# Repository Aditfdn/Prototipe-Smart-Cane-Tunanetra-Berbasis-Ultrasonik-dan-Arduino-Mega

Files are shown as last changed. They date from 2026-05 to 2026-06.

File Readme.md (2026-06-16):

<h1 align="center">Rancang Bangun Tongkat Pintar guna Membantu Mobilitas dan Keselamatan Penyandang Tuna Netra Berbasis ATmega2560 melalui Sistem Deteksi Halangan dan Peringatan Getar dalam Mendukung SDG No. 10 dan 11 (Reduced Inequalities & Sustainable Cities)</h1>

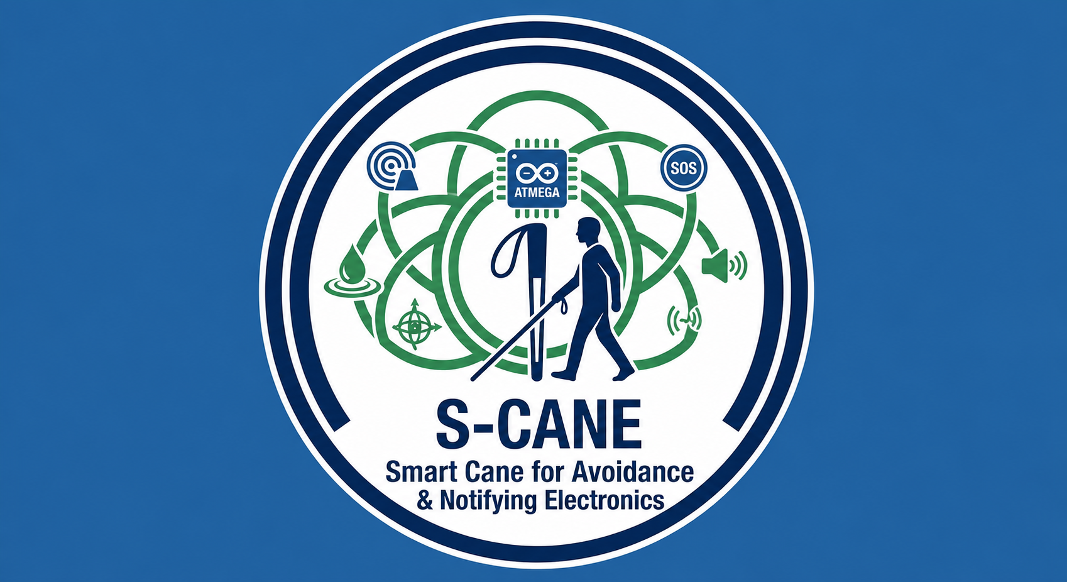
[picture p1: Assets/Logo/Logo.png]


## Deskripsi Proyek
Proyek ini mengembangkan **Tongkat Pintar (Smart White Cane)** berbasis **ATmega2560** yang dirancang untuk membantu mobilitas, keselamatan, dan kemandirian penyandang tuna netra dalam beraktivitas sehari-hari. Sistem mengintegrasikan teknologi deteksi lingkungan, peringatan taktil, serta komunikasi darurat secara real-time guna mendukung implementasi **SDG No. 10 (Reduced Inequalities)** dan **SDG No. 11 (Sustainable Cities and Communities)**.

Tongkat pintar ini memanfaatkan **sensor ultrasonik HC-SR04** untuk mendeteksi keberadaan halangan atau rintangan di depan pengguna. Selain itu, **Rain Sensor** digunakan untuk mendeteksi genangan air atau permukaan jalan yang basah sehingga pengguna dapat menghindari area yang berpotensi membahayakan. Informasi dari kedua sensor tersebut diproses oleh **mikrokontroler ATmega2560** dan diterjemahkan menjadi peringatan berupa getaran melalui **Motor Vibrator** serta bunyi melalui **Buzzer**, sehingga dapat dipahami dengan mudah oleh pengguna tuna netra.

Untuk meningkatkan aspek keselamatan, sistem dilengkapi **Panic Button** yang dapat ditekan pengguna ketika berada dalam kondisi darurat. Saat tombol ditekan, mikrokontroler akan mengaktifkan **modul SIM800L** untuk mengirimkan pesan notifikasi darurat ke akun **Telegram** yang telah terhubung sebelumnya. Fitur ini memungkinkan keluarga, pendamping, atau pihak terkait menerima informasi keadaan darurat secara cepat sehingga bantuan dapat segera diberikan.

Dengan menggabungkan sistem deteksi hambatan, deteksi genangan air, peringatan multimodal, dan komunikasi darurat berbasis Telegram, tongkat pintar ini diharapkan mampu meningkatkan aksesibilitas, keamanan, dan kualitas hidup penyandang tuna netra dalam beraktivitas di lingkungan perkotaan yang inklusif dan berkelanjutan.

## Tujuan Proyek

1. Merancang alat bantu jalan adaptif guna meningkatkan mobilitas mandiri dan keamanan penyandang tuna netra di lingkungan luar ruangan (outdoor).
2. Mengintegrasikan sensor ultrasonik (HC-SR04) dan rain sensor untuk mendeteksi rintangan fisik serta genangan air di jalan secara real-time.
3. Menerapkan sistem umpan balik ganda berupa peringatan getar (motor vibrator) dan suara (buzzer) yang intuitif bagi indra peraba dan pendengaran pengguna.
4. Menyediakan fitur keselamatan darurat berbasis GSM (SIM800L) untuk mengirimkan SMS peringatan otomatis secara real-time saat pengguna menekan tombol panik atau terdeteksi jatuh oleh sensor MPU-6050.
5. Mendukung pencapaian target SDGs global, khususnya SDG 9 (Industry, Innovation, and Infrastructure), SDG 10 (Reduced Inequalities), dan SDG 11 (Sustainable Cities and Communities).

## Support By :
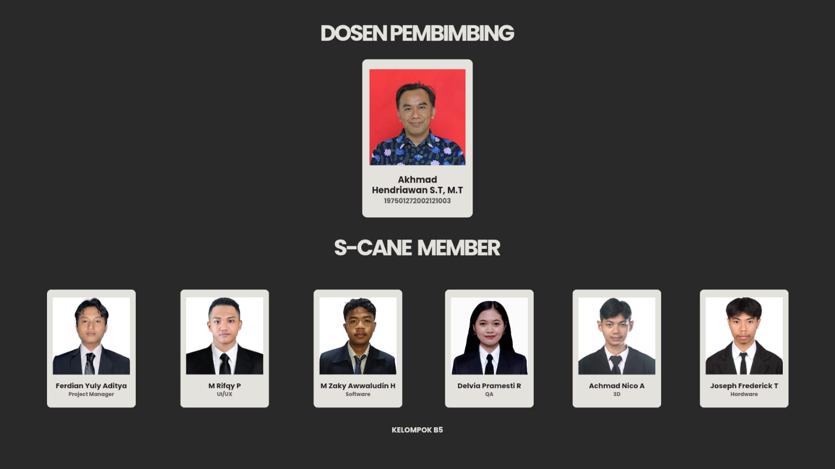
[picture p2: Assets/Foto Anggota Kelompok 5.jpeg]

> * Dosen Pengampu: Akhmad Hendriawan ST., MT. (NIP. 197501272002121003)
> * Mata Kuliah: Mikrokontroler
> * Program Studi: D4 Teknik Elektronika
> * Politeknik Elektronika Negeri Surabaya

## Anggota Tim

| Foto | NRP | Nama | Jobdesk | Akun |
| :---: | :---: | :---: | :---: | :---: |
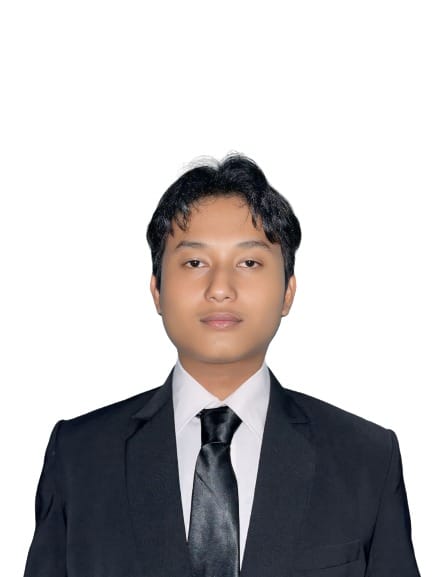
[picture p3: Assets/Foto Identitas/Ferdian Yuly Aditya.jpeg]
|  | 2124600054 | Ferdian Yuly Aditya | Project Manager | [Aditfdn](https://github.com/Aditfdn) |
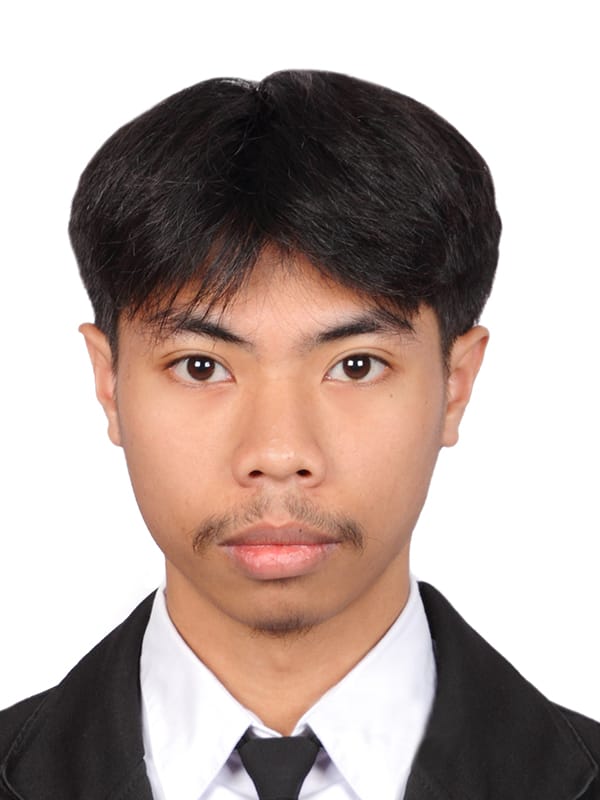
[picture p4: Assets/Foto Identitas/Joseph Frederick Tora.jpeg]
|  | 2124600039 | Joseph Frederick Tora  | Hardware Specialist | [josephtora](https://github.com/josephtora) |
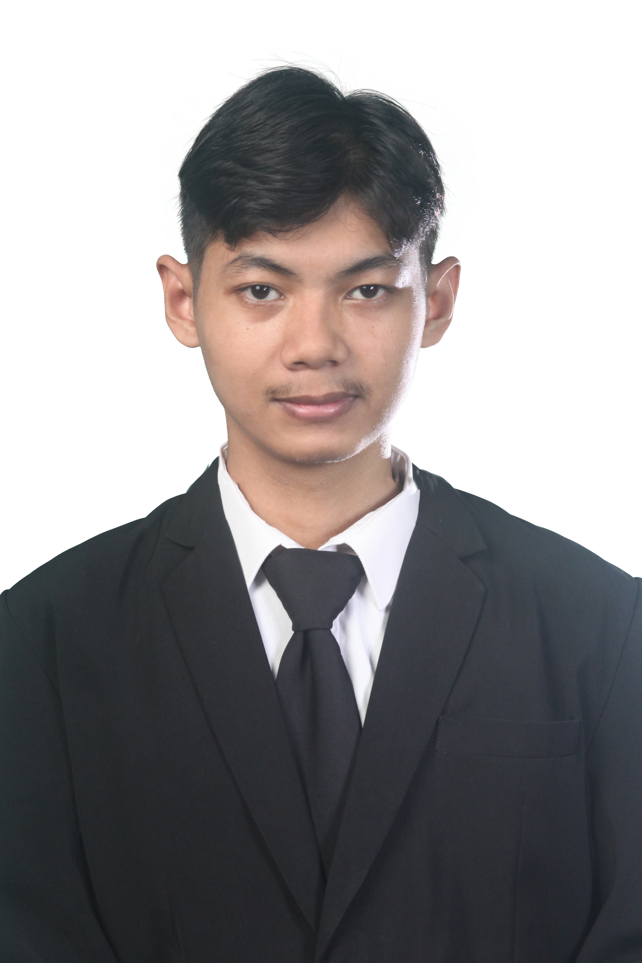
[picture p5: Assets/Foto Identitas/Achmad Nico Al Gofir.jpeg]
|  | 2124600052 | Achmad Nico Al Gofir | 3D Designer | [Oc1nn](https://github.com/Oc1nn) |
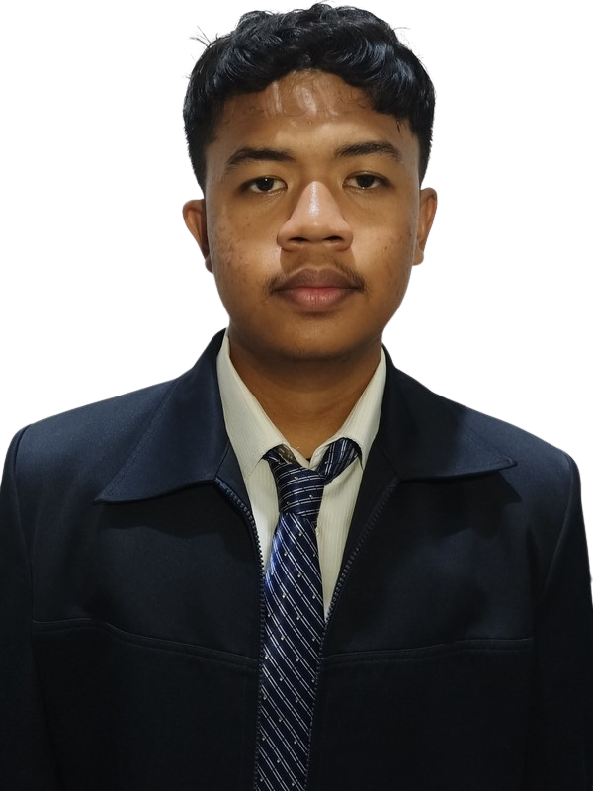
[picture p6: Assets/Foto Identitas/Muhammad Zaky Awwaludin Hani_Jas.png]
|  | 2124600055 | Muhammad Zaky Awwaludin Hani | Progammer | [Cheesejek](https://github.com/CheeseJek) |
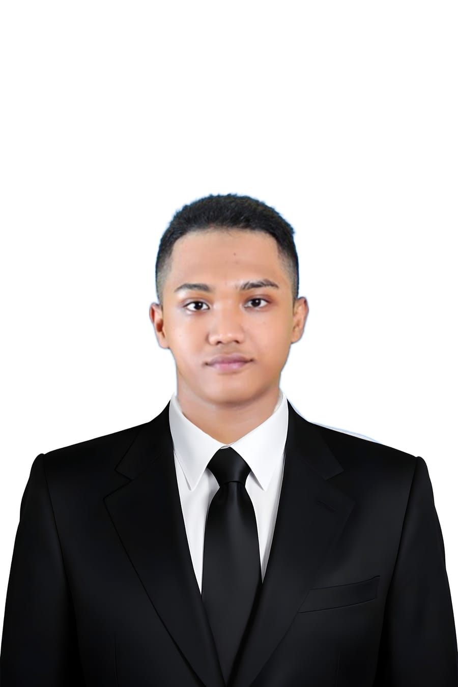
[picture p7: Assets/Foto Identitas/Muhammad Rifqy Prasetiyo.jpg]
|  | 2124600050 | Muhammad Rifqy Prasetiyo| UI/UX Designer | [Rifqypaypal](https://github.com/Rifqypaypal) |
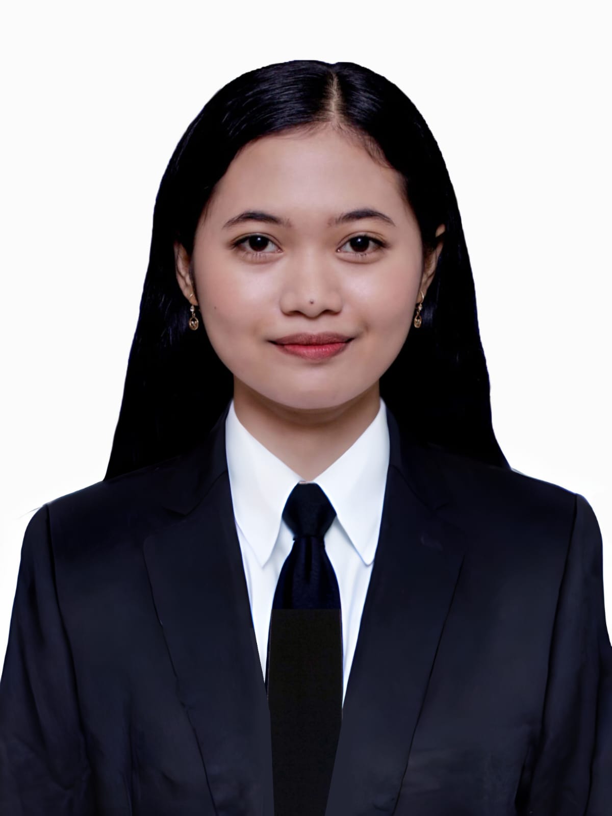
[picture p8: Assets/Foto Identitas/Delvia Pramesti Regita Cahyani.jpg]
|  | 2124600060 | Delvia Pramesti Regita Cahyani | QA | [delviap](https://github.com/delviap) |

### 🎬 Video Iklan & Promosi Produk

Simak video promosi sinematik S-CANE di bawah ini untuk melihat bagaimana teknologi inklusif berbasis ATmega2560 ini bekerja dalam membantu mobilitas mandiri penyandang tunanetra secara nyata:

https://github.com/user-attachments/assets/74869555-962a-41be-98e7-b088846499c1

> 💡 **Informasi Video:** Video promosi ini mencakup latar belakang permasalahan mobilitas disabilitas, visualisasi desain fisik casing 3D, serta demonstrasi langsung penanganan kondisi darurat (SOS) yang terintegrasi dengan Telegram pendamping.

## Komponen
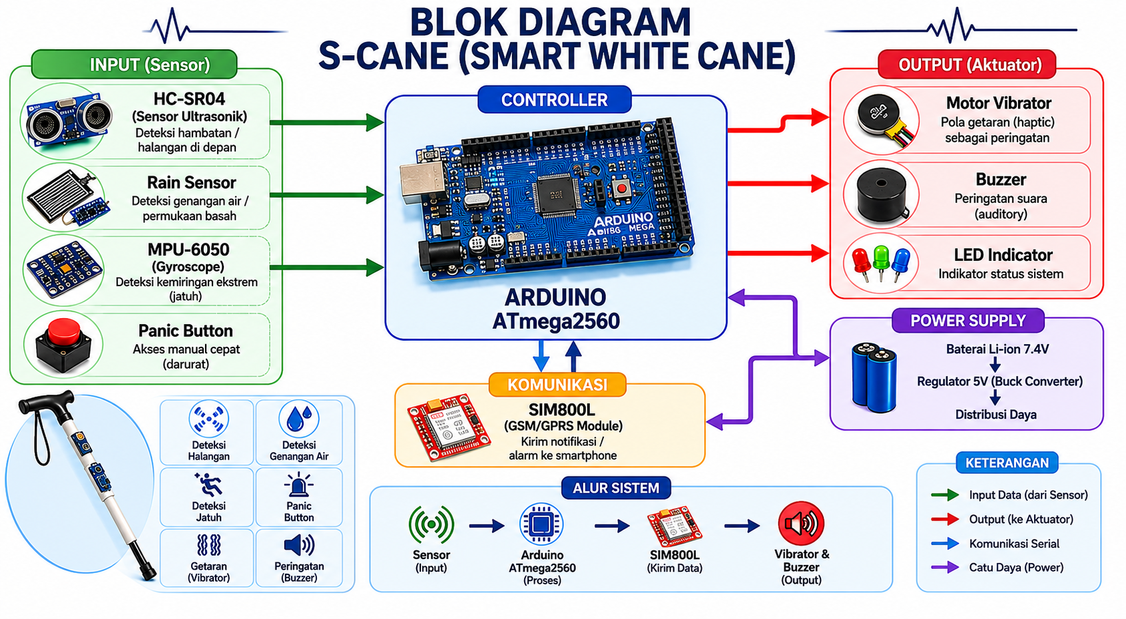
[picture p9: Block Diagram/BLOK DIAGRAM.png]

> * Rain Sensor
> * Motor Vibrator
> * Arduino ATmega 2560
> * HC-SR04 / Sensor Ultrasonik
> * MPU-6050 / Sensor Gyroscope
> * Buzzer
> * Button / Panic Button
> * SIM800L

## 🎨 3D Design & Prototyping
Berikut adalah hasil rancangan 3D dari S-CANE yang dikembangkan menggunakan software [Sebutkan Software, misal: Autodesk Inventor]:

| Tampilan Depan | Tampilan Samping |
| :---: | :---: |
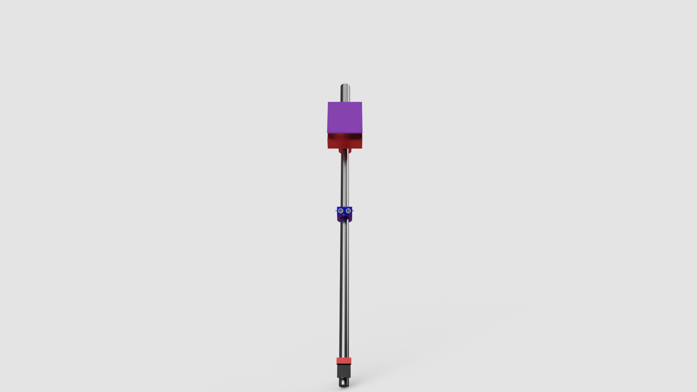
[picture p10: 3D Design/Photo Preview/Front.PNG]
Desain 1
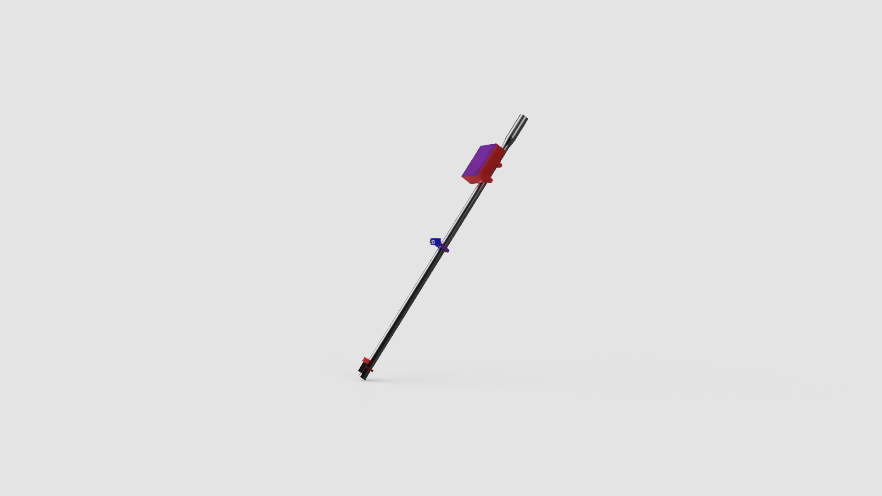
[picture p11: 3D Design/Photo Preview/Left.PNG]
Desain 2
|  |  |

> *Catatan: Desain ini dibuat untuk memastikan ergonomi dan penempatan sensor yang optimal pada tongkat.*

## 📱 UI/UX Design & Simulasi Sistem

Untuk mendukung fungsionalitas S-CANE, dikembangkan juga sebuah konsep antarmuka (UI/UX) aplikasi mobile yang berfungsi sebagai pusat kendali, monitoring status baterai, serta pelacakan lokasi pengguna tongkat secara real-time.

### 🎨 Alur Kerja Antarmuka (User Flow)
Sistem antarmuka dirancang dengan mengutamakan aksesibilitas tinggi dan kemudahan navigasi bagi keluarga atau pendamping tunanetra:

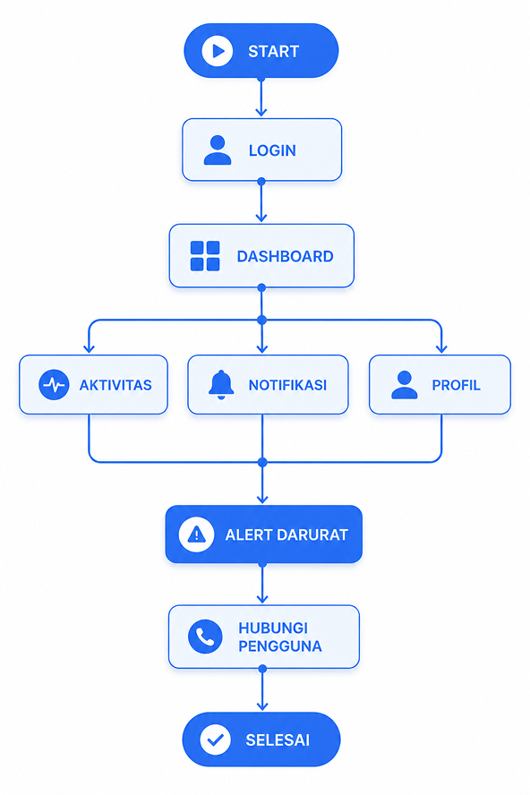
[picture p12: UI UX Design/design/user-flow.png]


1. **Dashboard Utama:** Menampilkan status konektivitas tongkat, indikator baterai ATmega2560, dan kondisi cuaca di sekitar pengguna (terintegrasi dengan *Rain Sensor*).
2. **Sistem Notifikasi Darurat:** Antarmuka khusus yang akan memicu alarm di sisi pendamping secara otomatis ketika *Panic Button* pada tongkat ditekan atau saat sensor MPU-6050 mendeteksi pengguna terjatuh.
3. **Integrasi Telegram Bot:** Simulasi pengiriman data koordinat dan pesan teks otomatis dari modul SIM800L ke aplikasi Telegram.

### 📐 Galeri Antarmuka
| Splash Screen & Login | Dashboard Monitoring | Notifikasi Darurat |
| :---: | :---: | :---: |
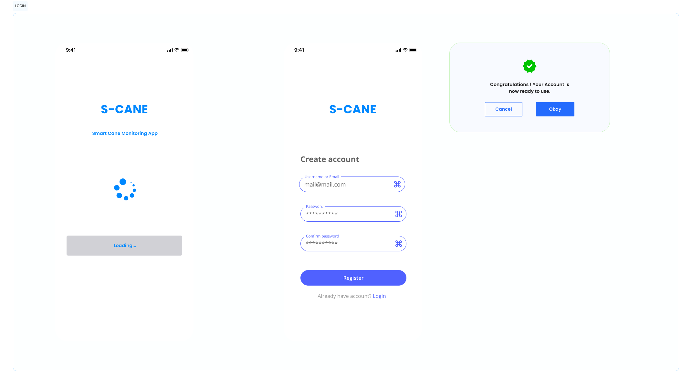
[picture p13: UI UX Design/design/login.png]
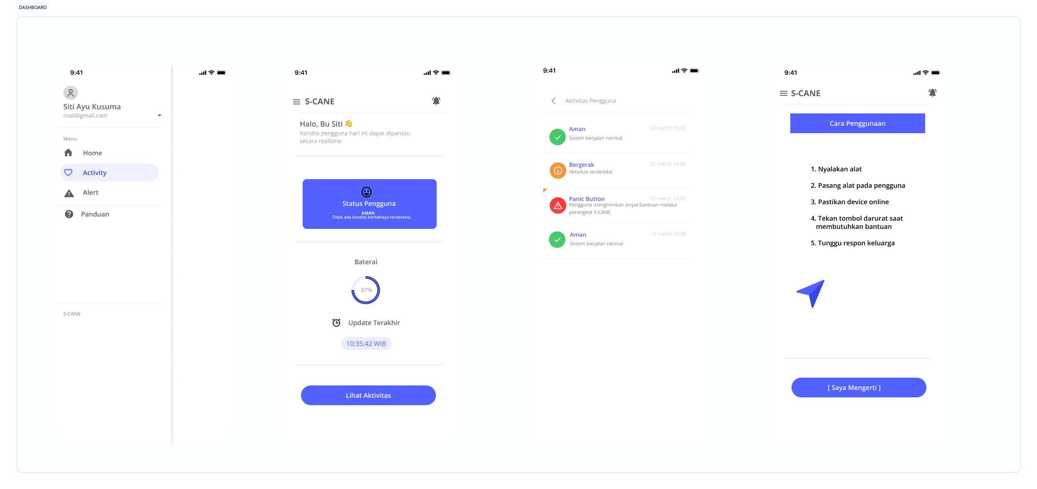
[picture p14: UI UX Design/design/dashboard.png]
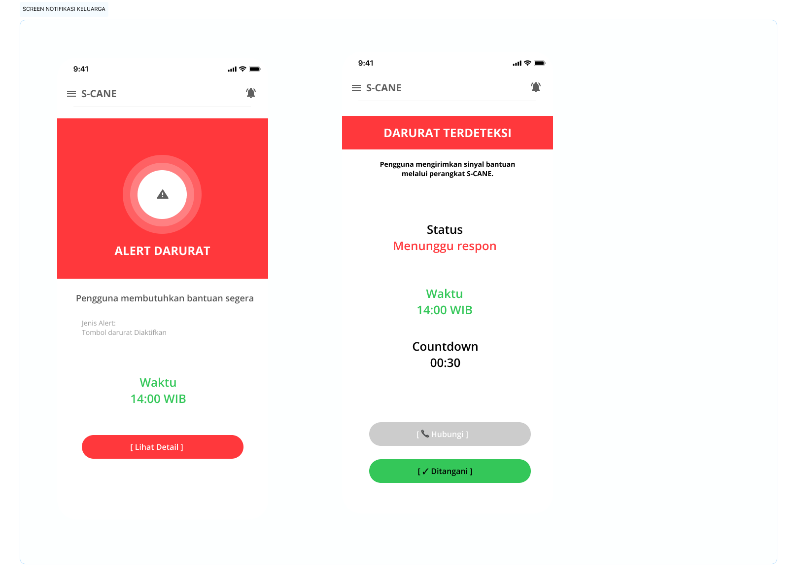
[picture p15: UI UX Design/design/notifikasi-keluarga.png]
|  |  |  |

### 📱 Panduan Penggunaan Aplikasi Mobile (UI/UX)

Desain antarmuka aplikasi mobile S-CANE tersedia secara lengkap dan interaktif di Figma. Aplikasi ini berfungsi sebagai pusat kendali bagi keluarga atau pendamping tunanetra untuk memantau kondisi pengguna tongkat secara real-time.

🔗 **Akses Desain Figma:** [S-CANE Design Mobile – Figma](https://www.figma.com/design/aeiLbA82CAR6ZKnhpcHcCP/S-CANE-Design-Mobile?node-id=0-1&t=lzUT9AXG1RDVlpGS-0)

### 🗺️ Alur Penggunaan Aplikasi

#### 1. 🚀 Splash Screen & Login
- Buka aplikasi, tampilan *splash screen* S-CANE akan muncul secara otomatis.
- Masukkan acc dan password kalian serta masukkan identitas kalian yang berisikan nama dan nomor (terdaftar telegram).
- Setelah autentikasi berhasil, pengguna akan diarahkan ke halaman **Dashboard Utama**.

#### 2. 📊 Dashboard Monitoring
- Dashboard menampilkan **status koneksi** antara aplikasi dan perangkat S-CANE secara real-time.
- Tersedia indikator **level baterai** ATmega2560 agar pendamping mengetahui kapan perangkat perlu diisi ulang.
- Kondisi lingkungan sekitar pengguna (basah/kering) yang terdeteksi oleh *Rain Sensor* ditampilkan sebagai **status cuaca jalan**.
- Seluruh informasi diperbarui secara otomatis tanpa perlu me-*refresh* halaman.

#### 3. 🆘 Sistem Notifikasi Darurat
- Ketika pengguna menekan **Panic Button** pada tongkat, aplikasi akan langsung menerima notifikasi darurat yang dikirim melalui modul **SIM800L** via Telegram.
- Notifikasi yang sama juga dipicu secara otomatis apabila sensor **MPU-6050** mendeteksi kondisi pengguna terjatuh.
- Halaman notifikasi darurat menampilkan **waktu kejadian**, **status peringatan**, serta panduan tindakan yang dapat segera diambil oleh pendamping.

#### 4. 🤖 Integrasi Telegram Bot
- Semua pesan darurat dan data status dikirimkan secara otomatis ke **akun Telegram** yang telah ditautkan pada saat login.
- Pastikan koneksi internet pada perangkat SIM800L aktif agar notifikasi dapat terkirim tanpa hambatan.
- Pendamping tidak perlu membuka aplikasi secara manual — notifikasi Telegram akan muncul langsung di layar kunci perangkat pendamping.

### ⚙️ Persyaratan Penggunaan
- Akun Telegram yang aktif untuk menerima notifikasi darurat.
- Kartu SIM dengan kuota data aktif yang terpasang pada modul **SIM800L** di perangkat S-CANE.
- Pastikan perangkat S-CANE dalam kondisi menyala dan baterai terisi cukup sebelum digunakan.

> 💡 **Catatan:** Seluruh tampilan antarmuka di atas merupakan konsep desain UI/UX yang dapat diakses dan dieksplorasi secara interaktif melalui tautan Figma di atas. Implementasi aplikasi mobile secara penuh merupakan pengembangan lanjutan dari proyek ini.

### 🎥 Video Simulasi & Demo UI/UX
Berikut adalah video demonstrasi interaktif prototipe dan jalannya aplikasi pendukung S-CANE:

https://github.com/user-attachments/assets/26122700-60ff-4c79-a8bb-ca77b9de54d8

## 🎬 Video Simulasi Sistem Keseluruhan

Selain pemodelan antarmuka, pengujian fungsionalitas logika program ATmega2560 pada proyek S-CANE ini juga didokumentasikan melalui simulasi interaktif. Video ini menampilkan bagaimana seluruh sensor (HC-SR04, Rain Sensor, MPU-6050) merespons lingkungan dan mengirimkan data secara sinkron ke aktuator serta sistem peringatan.

### 🕹️ Link Simulasi Aktif (Wokwi)

Anda dapat melihat, menjalankan, dan menguji logika program ATmega2560 pada sirkuit S-CANE secara langsung melalui browser tanpa perlu perangkat keras fisik. Klik tombol di bawah ini untuk membuka simulator:



> 💡 **Cara Menguji Alat di Wokwi:**
> 1. Klik tombol **Launch Wokwi Simulator** di atas.
> 2. Klik tombol **Start Simulation (Ikon Play Hijau)** pada halaman Wokwi.
> 3. Klik pada komponen **HC-SR04** untuk menggeser slider jarak halangan, atau tekan **Panic Button** untuk melihat respons dari Buzzer dan Motor Vibrator, klik **MPU** untuk melihat kemiringan gyroscope, serta 2 **Potensio** yang satu sebelah kiri **Rain Sensor** dan sebelah kanan sebagai Data Dummy baterai pada **UI/UX** .

### 📺 Demo Simulasi Alat

https://github.com/user-attachments/assets/4040b269-2278-43a4-b501-594f7b9bb5d2

> 💡 **Informasi Pengujian:** > * **Simulasi Input:** Simulasi pembacaan jarak rintangan dan deteksi kondisi jalan basah/genangan air.
> * **Simulasi Output:** Respons kedipan frekuensi buzzer, kekuatan getaran motor vibrator, serta simulasi pengiriman instruksi AT Command oleh modul GSM SIM800L.

## ⚙️ Simulasi Sistem Keseluruhan

Pengujian fungsionalitas dan logika program **ATmega2560** pada proyek S-CANE didokumentasikan sepenuhnya melalui rekaman video simulasi. Video ini menampilkan bagaimana seluruh sistem dari 3D, Ui Ux hingga sensor (HC-SR04, Rain Sensor, MPU-6050) merespons lingkungan dan berinteraksi secara sinkron dengan komponen output.

### 🎥 Video Demonstrasi Simulasi Alat
Berikut adalah rekaman jalannya pengujian simulasi sistem S-CANE dari awal hingga akhir:

https://github.com/user-attachments/assets/8619169c-2171-4413-95fd-638ff369f83f

---

### 🔍 Cakupan Pengujian dalam Video:
* **Simulasi Deteksi Rintangan:** Demonstrasi respons frekuensi suara *Buzzer* dan kekuatan *Motor Vibrator* saat sensor ultrasonik HC-SR04 mendeteksi objek dalam jarak dekat dan kritis.
* **Simulasi Deteksi Cuaca/Jalan Basah:** Respons sistem saat *Rain Sensor* mendeteksi adanya genangan air atau permukaan jalan yang basah.
* **Simulasi Kondisi Darurat (SOS):** Pengujian logika pengiriman pesan darurat otomatis ke UI/UX dan Telegram pendamping ketika *Panic Button* ditekan atau ketika sensor *MPU-6050* mendeteksi simulasi pengguna terjatuh.

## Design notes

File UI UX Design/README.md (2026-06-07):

# S-CANE UI/UX Design

## Overview

S-CANE (Smart Cane for Avoidance and Notifying Electronics) merupakan proyek pengembangan antarmuka aplikasi mobile yang digunakan untuk menampilkan informasi dari sistem Smart Cane.

Dokumentasi ini berisi desain antarmuka pengguna (UI) dan alur interaksi pengguna (UX) yang digunakan pada aplikasi S-CANE.

---

## Available Screens

### Splash Screen

Menampilkan identitas aplikasi saat pertama kali dijalankan.

### Login Screen

Digunakan untuk autentikasi pengguna sebelum masuk ke sistem.

### Dashboard

Halaman utama yang menampilkan informasi dan navigasi aplikasi.

### Profile Screen

Menampilkan informasi akun pengguna.

### Alert Screen

Menampilkan peringatan atau kondisi yang membutuhkan perhatian pengguna.

### Family Notification Screen

Menampilkan informasi notifikasi yang diterima keluarga.

---

## Project Structure

```text
UI UX Design/
│
├── design/
│   ├── login.png
│   ├── dashboard.png
│   ├── profile.png
│   ├── alert.png
│   ├── notifikasi-keluarga.png
│   └── user-flow.png
│
├── docs/
│   ├── uiux-design.md
│   ├── user-flow.md
│   ├── design-system.md
│   └── prototype-link.md
│
├── simulasi/
|
└── README.md
```

## Documentation

| File | Description |
| --- | --- |
| uiux-design.md | Dokumentasi antarmuka pengguna |
| user-flow.md | Alur interaksi pengguna |
| design-system.md  | Panduan desain dan komponen |
| prototype-link.md | Link desain Figma |

---

## Design Tool

Figma

Prototype:
https://www.figma.com/design/aeiLbA82CAR6ZKnhpcHcCP/S-CANE-Design-Mobile

---

## Purpose

Dokumentasi ini dibuat sebagai bagian dari pengembangan proyek S-CANE dan digunakan sebagai referensi dalam proses implementasi antarmuka aplikasi.

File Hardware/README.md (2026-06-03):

# Schematic

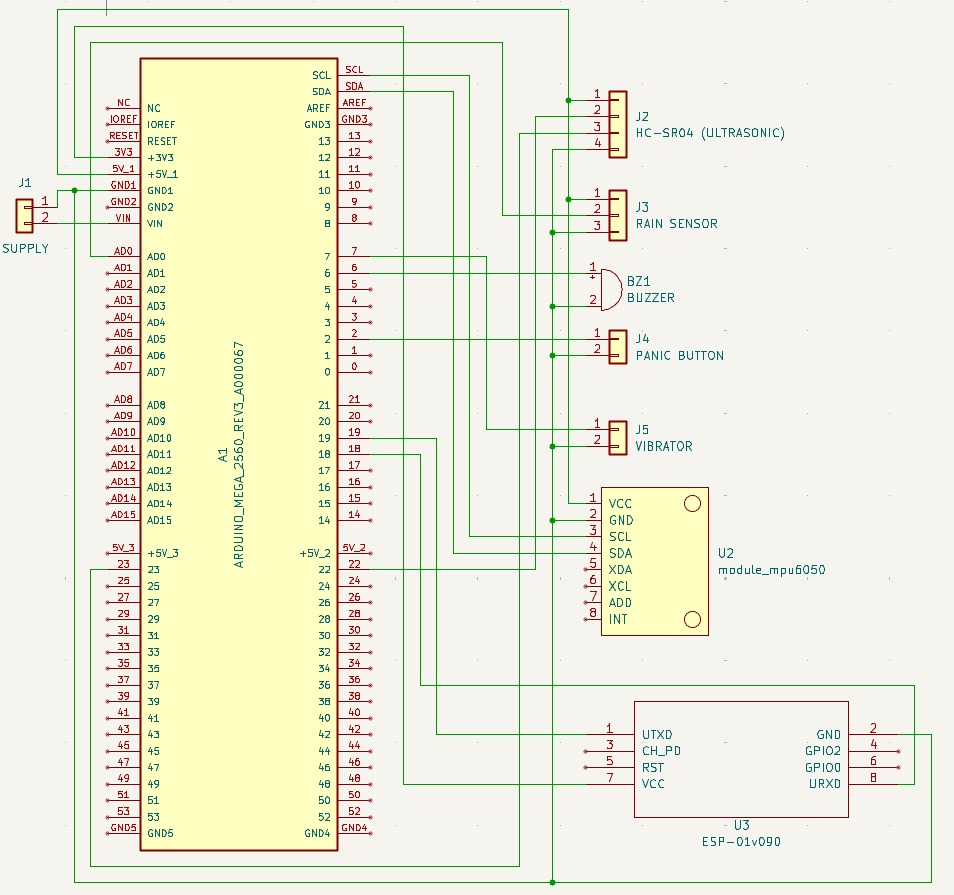
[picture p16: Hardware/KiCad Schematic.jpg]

# 3D View

## Top View
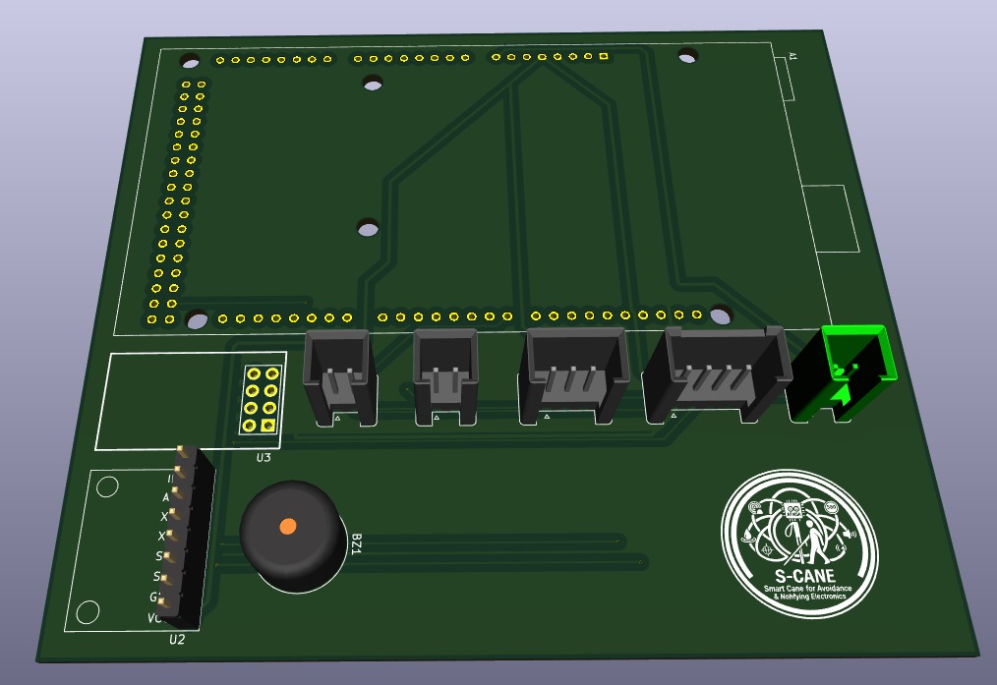
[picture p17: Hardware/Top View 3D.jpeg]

## Bottom View
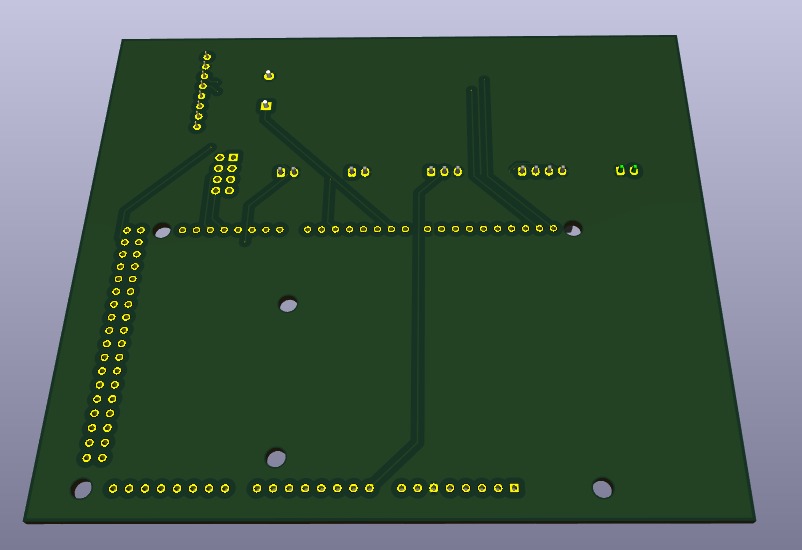
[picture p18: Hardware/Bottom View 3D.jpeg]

# PCB Layer

## Front & Back Layer
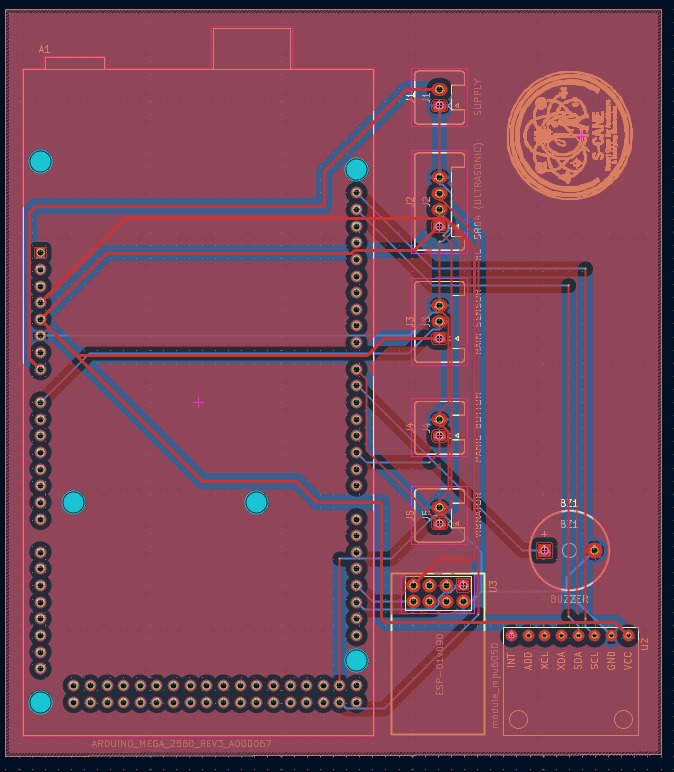
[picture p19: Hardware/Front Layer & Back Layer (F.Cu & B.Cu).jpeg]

## Front Layer
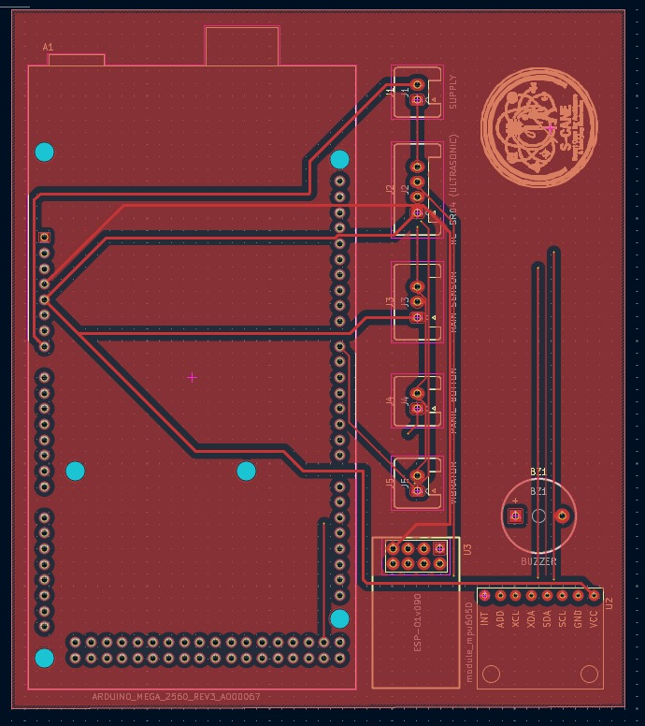
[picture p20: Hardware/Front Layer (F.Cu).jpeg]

## Back Layer
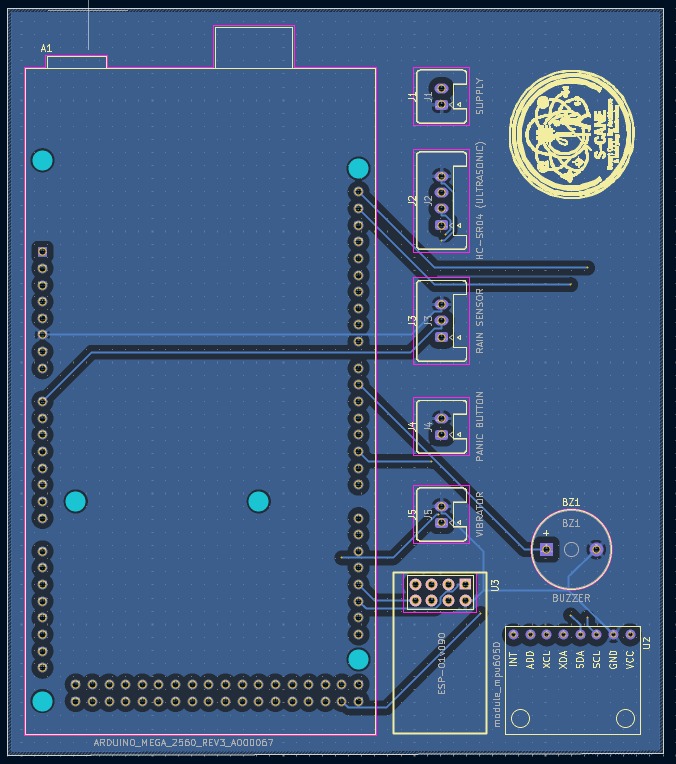
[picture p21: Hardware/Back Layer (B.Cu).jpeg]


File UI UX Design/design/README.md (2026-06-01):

# Design Assets

Folder ini berisi seluruh aset desain antarmuka aplikasi S-CANE.

## Screens

* login.png
* dashboard.png
* profile.png
* alert.png
* notifikasi-keluarga.png

## User Flow

* user-flow.png

Seluruh desain dibuat menggunakan Figma sebagai media perancangan antarmuka pengguna.

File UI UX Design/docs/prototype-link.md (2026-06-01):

# Prototype Link

## S-CANE Mobile Design Prototype

Link Figma:

https://www.figma.com/design/aeiLbA82CAR6ZKnhpcHcCP/S-CANE-Design-Mobile?node-id=0-1&t=hH0QHacxM52goHAf-1

## Deskripsi

Prototype ini berisi desain antarmuka aplikasi S-CANE yang digunakan sebagai media visualisasi sistem.

Halaman yang tersedia pada prototype:

* Splash Screen
* Login Screen
* Dashboard
* Profile Screen
* Screen Alert
* Screen Notifikasi Keluarga

## Tujuan

Prototype digunakan untuk:

1. Menampilkan rancangan antarmuka aplikasi.
2. Membantu proses evaluasi desain sebelum implementasi.
3. Menunjukkan alur interaksi pengguna pada sistem S-CANE.
4. Menjadi referensi pengembangan antarmuka aplikasi.

## Catatan

Desain pada Figma digunakan sebagai acuan utama dalam proses pengembangan tampilan aplikasi S-CANE.

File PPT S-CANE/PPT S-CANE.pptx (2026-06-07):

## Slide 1

SMART CANE

Detect, Alert, Protect.

B5

Alert,

Dosen Pengampu
Akhmad Hendriawan, ST.,MT
197501272002121003

Muhammad Rifqy Prasetiyo
2124600050
UI/UX Designer

Delvia Pramesti Regita Cahyani
2124600060
QA

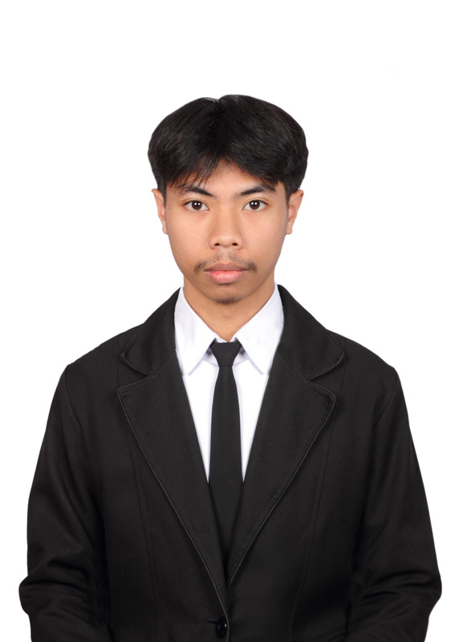
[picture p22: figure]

Joseph Fredercik Tora
2124600039
Hardware

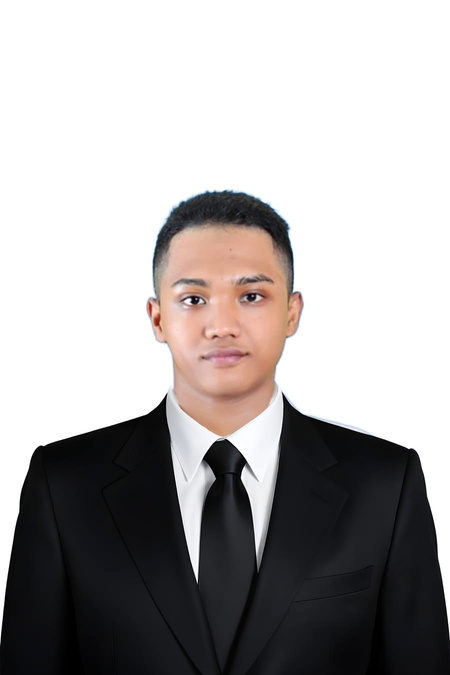
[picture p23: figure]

Achmad Nico Al Gofir
2124600052
3D Designer

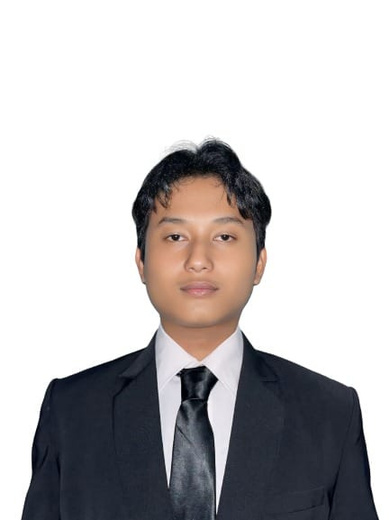
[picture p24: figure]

Ferdian Yuly Aditya
2124600054
Project Manager

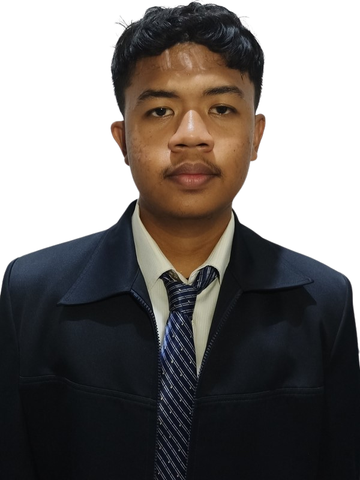
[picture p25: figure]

Muhammad Zaky Awwaludin H
2124600055
Progammer

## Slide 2

MIND-MAP

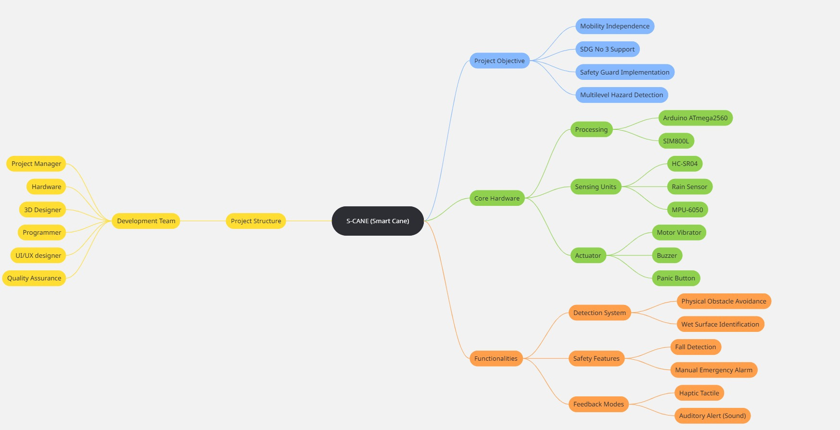
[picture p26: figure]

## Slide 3

Kesimpulan penting dari ketiga permasalahan tersebut adalah bahwa trotoar di berbagai wilayah belum memberikan ruang yang aman bagi penyandang tunanetra akibat alih fungsi lahan oleh parkir liar dan pedagang, buruknya pemeliharaan infrastruktur, serta kesalahan desain pembangunan guiding block yang justru menjebak dan membahayakan keselamatan. Hal ini menunjukkan masih lemahnya penegakan hukum dan minimnya pelibatan komunitas difabel dalam perencanaan fasilitas publik, sehingga hak aksesibilitas yang inklusif dan ramah bagi teman-teman disabilitas belum terpenuhi dengan layak.

THE PROBLEM

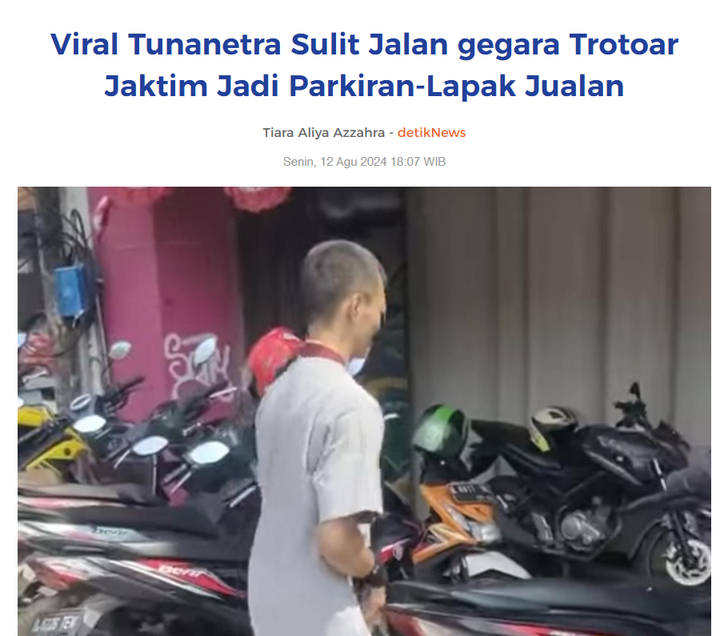
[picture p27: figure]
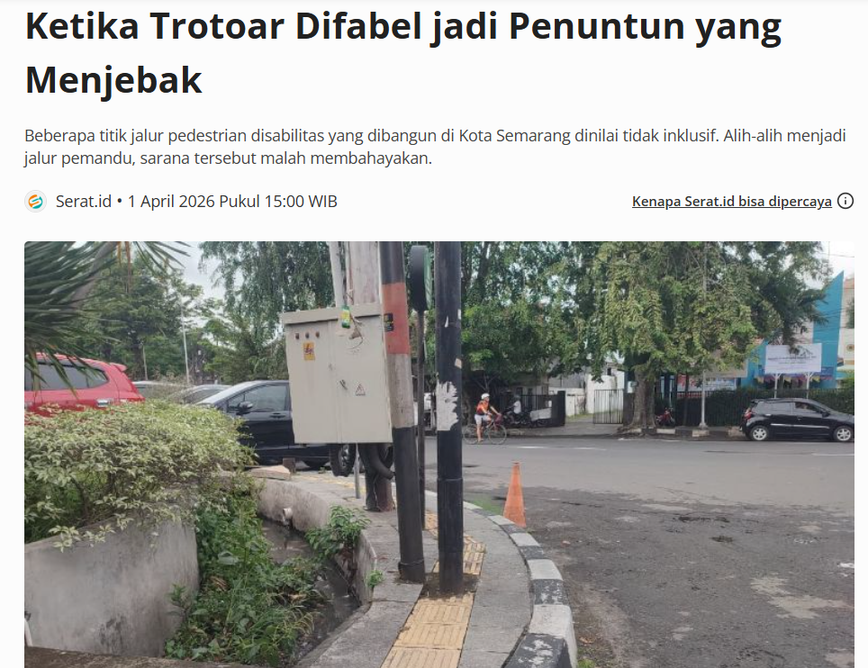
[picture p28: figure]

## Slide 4

ROOT CAUSE & MATRIK KEPUTUSAN

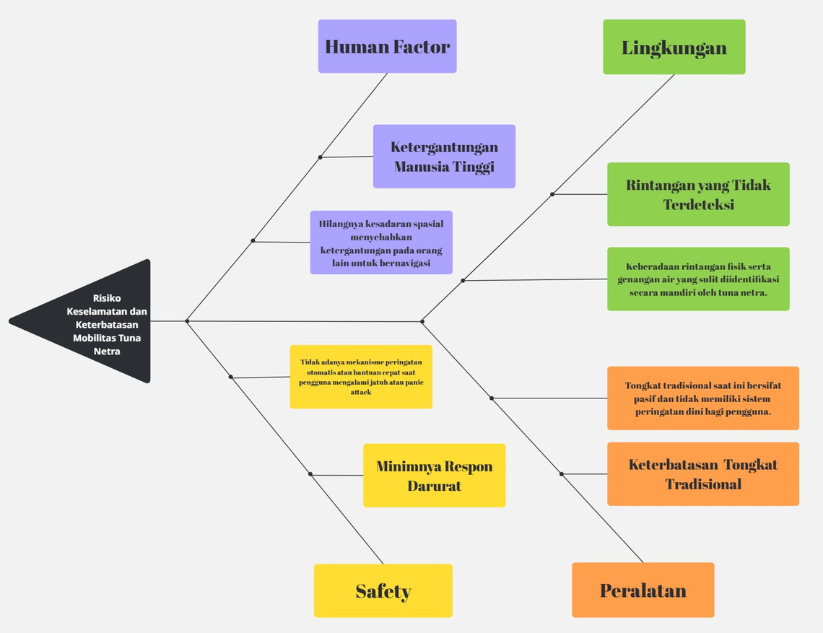
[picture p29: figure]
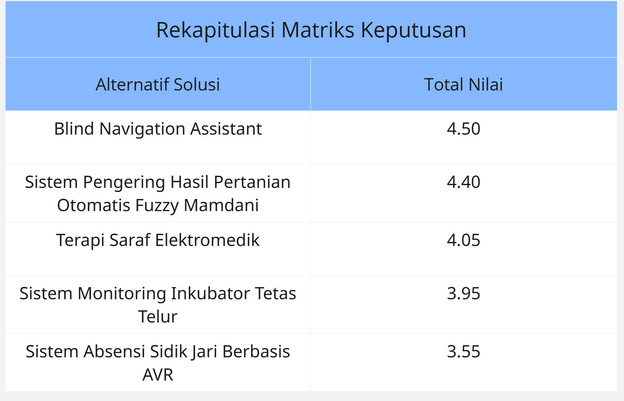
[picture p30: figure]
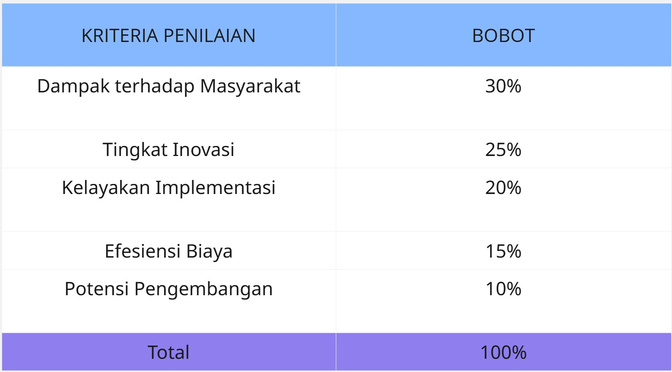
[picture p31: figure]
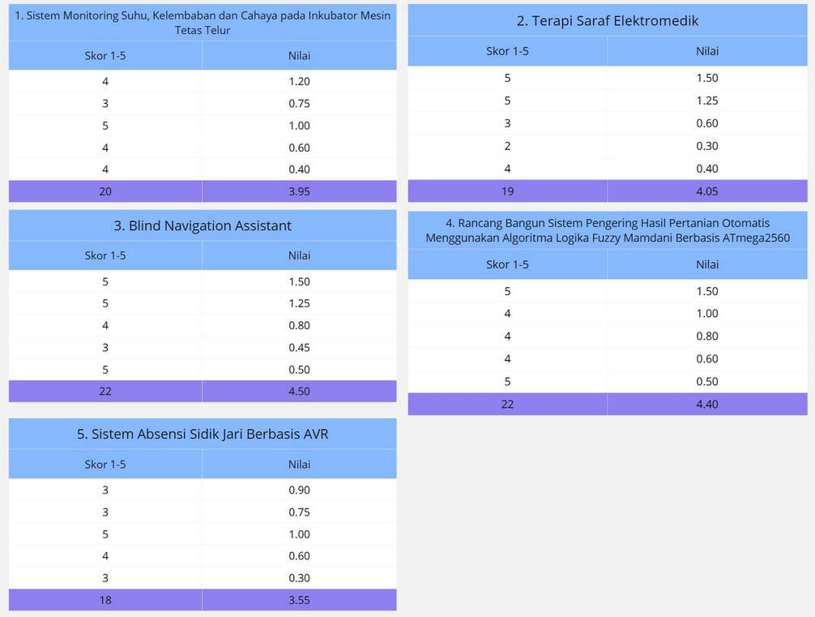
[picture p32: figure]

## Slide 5

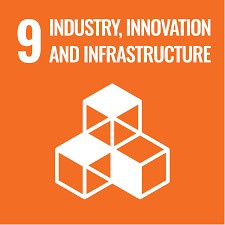
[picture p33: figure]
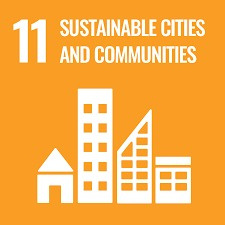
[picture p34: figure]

SDG 9 - Industry, Innovation, and Infrastructure

Target 9.5 :
  - Enhance scientific research and upgrade technological capabilities.
Justifikasi :
  - S-CANE mengintegrasikan mikrokontroler ATmega2560 dengan IoT (ESP8266) sebagai bentuk inovasi teknologi tepat guna untuk memodernisasi alat bantu konvensional.

SDG 10 - Reduced Inequalities

Target 10.2 :
  - Empower and promote the social, economic, and political inclusion of all, irrespective of disability.
Justifikasi :
  - S-CANE bertindak sebagai assistive technology yang memandirikan mobilitas tuna netra, mengurangi ketergantungan pada orang lain, dan memangkas kesenjangan sosial.

SDG 11 - Sustainable Cities and Communities

Target 11.2 :
  - Provide access to safe, affordable, accessible and sustainable transport systems for all, notably older persons and persons with disabilities.
Justifikasi :
  - Melalui deteksi halangan otomatis dan genangan air, proyek ini mendukung terciptanya infrastruktur lingkungan kota yang inklusif dan aman bagi kelompok rentan.

SDGs IMPACT

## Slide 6

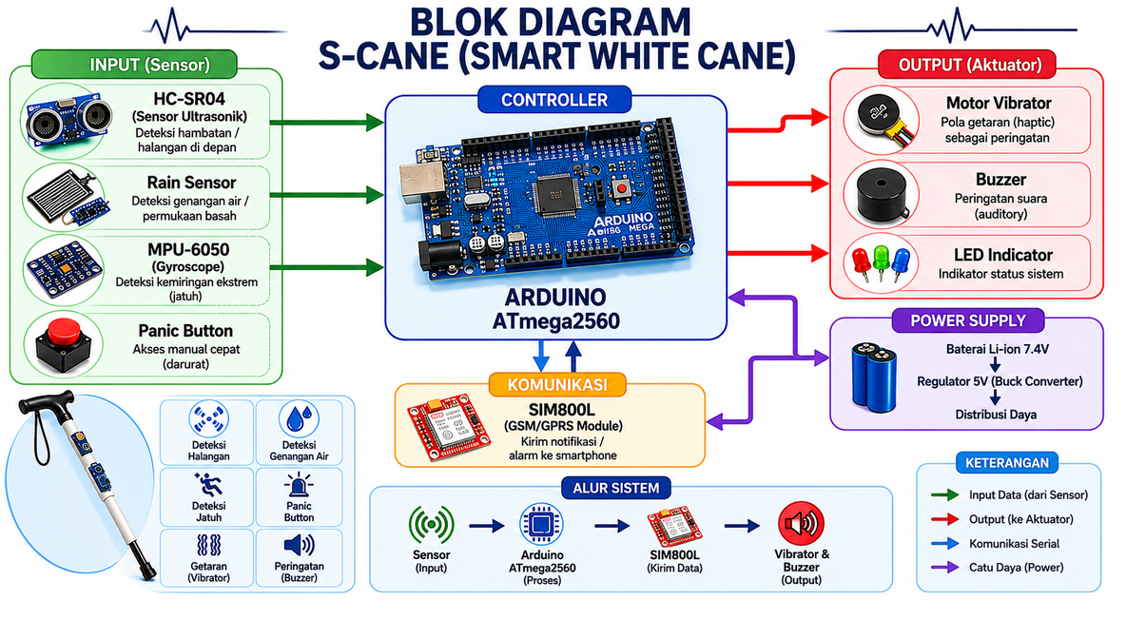
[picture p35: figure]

BLOK DIAGRAM

TABEL I/O

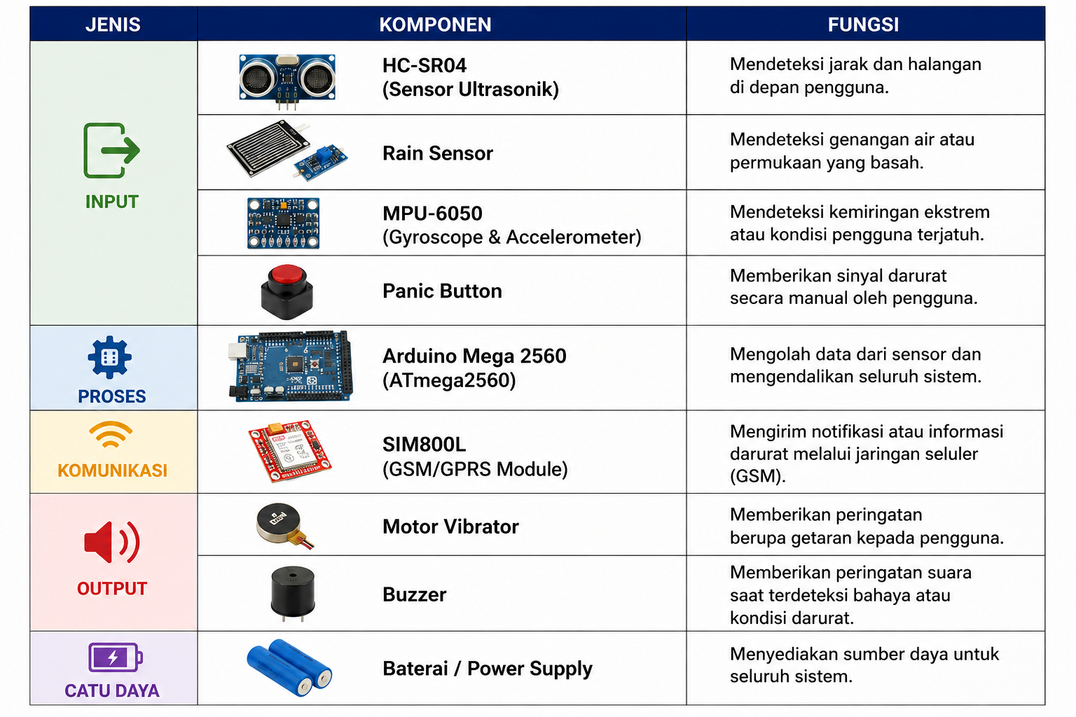
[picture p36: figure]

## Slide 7

UI UX Design

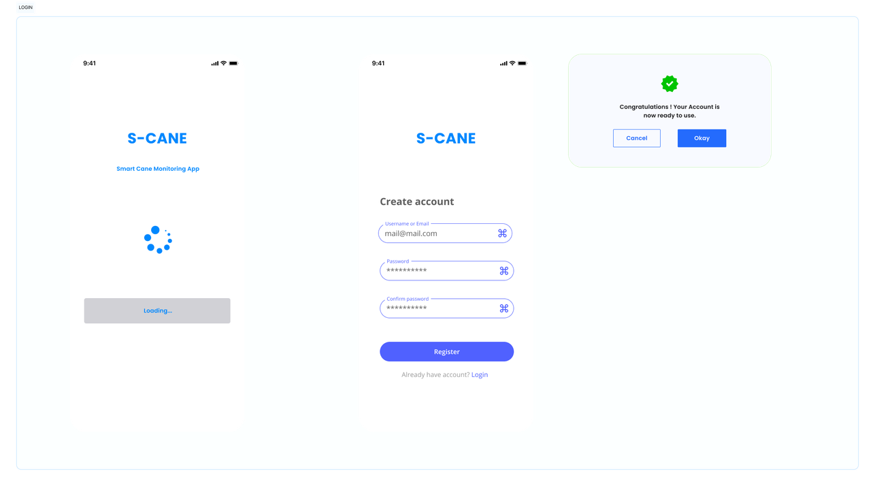
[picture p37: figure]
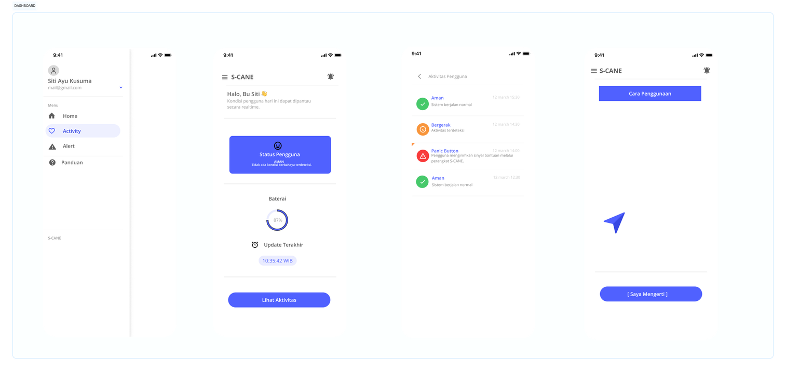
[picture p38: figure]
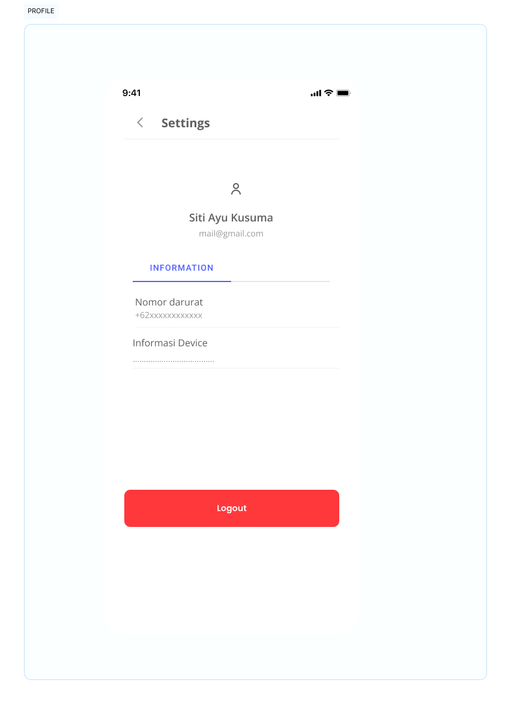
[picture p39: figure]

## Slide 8

Pin Mapping & Anggaran

KOMPONEN | JUMLAH | HARGA
Arduino Mega 2560 | 1 | Rp170.000
Sensor Ultrasonik HC-SR04 | 1 | Rp18.000
Modul Sensor Hujan (Rain Sensor) | 1 | Rp18.000
Sensor Gyroscope MPU-6050 | 1 | Rp30.000
SIM800L | 1 | Rp70.000
Mini Push Button (Panic) | 1 | Rp1.000
Active Buzzer 5V | 1 | Rp3.000
Coin Vibration Motor 5V | 1 | Rp5.000
Baterai 18650 & Holder | 1 | Rp40.000
Kabel Jumper, PCB Bolong dan lain lain | 1 | Rp25.000
Total | 10 | Rp380.000

KOMPONEN | PIN KOMPONEN | PIN ATmega2560 (Arduino Mega)
HC-SR04 | TRIG ECHO | 22 23
Rain Sensor (Simulasi: Potensio) | SIG / AO | A0
MPU-6050 (Gyroscope) | SDA SCL | 20 (SDA) 21 (SCL)
Panic Button | Out / Kaki 1 | 2 (INT0)
Motor Vibrator (Simulasi: LED) | Anoda (+) | 7 (PWM)
Buzzer | Positif (+) | 6 (PWM)
SIM800l | TX RX | 18 (TX1) 19 (RX1)

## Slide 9

ACTIVITY LOG


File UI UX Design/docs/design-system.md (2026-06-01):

# Design System Documentation

## Warna

### Biru

Digunakan pada:

* Tombol utama
* Header
* Informasi status

Tujuan:
Memberikan kesan aman dan konsisten.

### Merah

Digunakan pada:

* Alert
* Peringatan

Tujuan:
Menarik perhatian pengguna terhadap kondisi penting.

### Putih

Digunakan sebagai warna latar utama.

Tujuan:
Menjaga tampilan tetap bersih dan mudah dibaca.

---

# Typography

Jenis huruf yang digunakan mengikuti standar antarmuka mobile modern dengan tampilan sederhana dan mudah dibaca.

---

# Komponen Utama

## Button

Digunakan untuk:

* Login
* Logout
* Tindakan pada Alert

## Card

Digunakan untuk:

* Menampilkan informasi
* Menampilkan status

## Navigation

Digunakan untuk berpindah antar halaman pada aplikasi.

---

# Konsistensi Desain

Seluruh halaman menggunakan:

* Warna utama yang sama
* Bentuk tombol yang seragam
* Tata letak sederhana
* Struktur informasi yang konsisten

Hal ini bertujuan untuk meningkatkan kemudahan penggunaan aplikasi.

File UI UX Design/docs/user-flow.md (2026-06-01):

# User Flow Documentation

## Alur Penggunaan Aplikasi

Splash Screen
↓
Login
↓
Dashboard

Dari Dashboard pengguna dapat membuka:

* Profile
* Alert
* Notifikasi Keluarga

---

## Skenario Penggunaan

### Skenario 1

1. Pengguna membuka aplikasi.
2. Splash Screen ditampilkan.
3. Pengguna melakukan Login.
4. Sistem menampilkan Dashboard.

### Skenario 2

1. Pengguna berada pada Dashboard.
2. Sistem menampilkan Alert.
3. Pengguna melihat informasi kondisi yang diberikan sistem.

### Skenario 3

1. Sistem mengirimkan notifikasi.
2. Informasi ditampilkan pada Screen Notifikasi Keluarga.
3. Keluarga dapat melihat detail kondisi yang diterima.

### Skenario 4

1. Pengguna membuka halaman Profile.
2. Pengguna melihat informasi akun.
3. Pengguna dapat melakukan Logout.

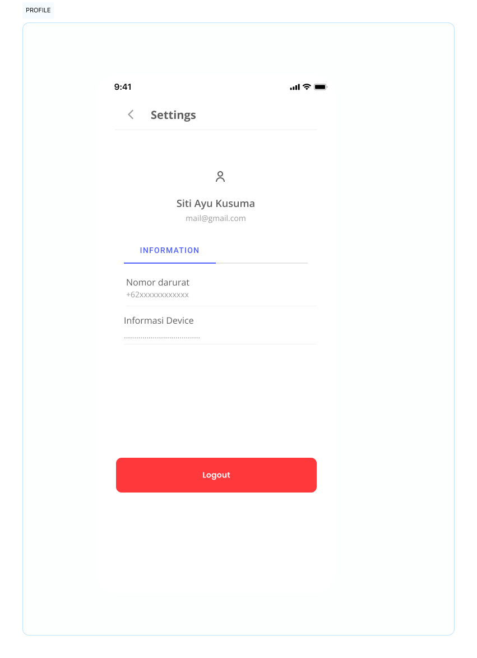
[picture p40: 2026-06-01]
UI UX Design/design/profile.png

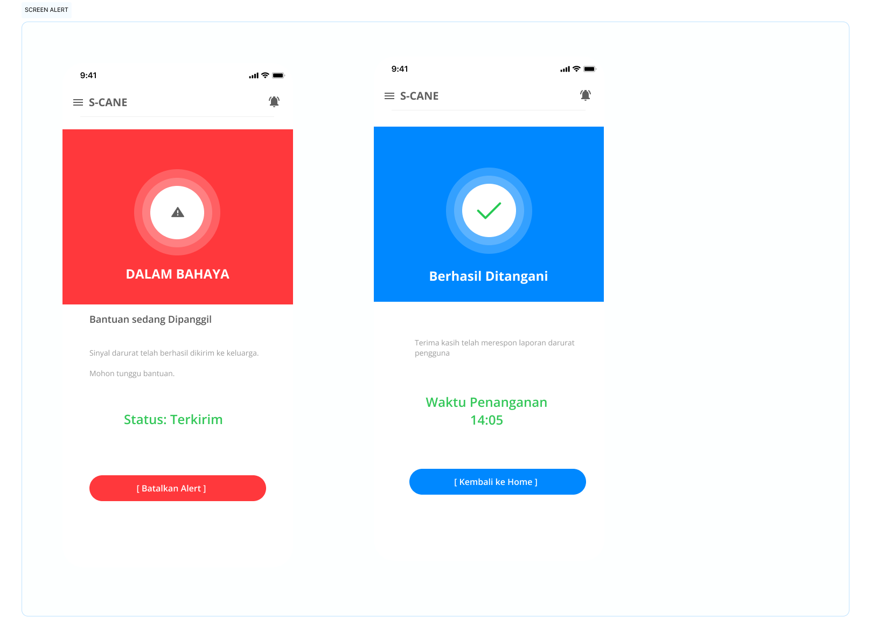
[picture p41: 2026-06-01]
UI UX Design/design/alert.png

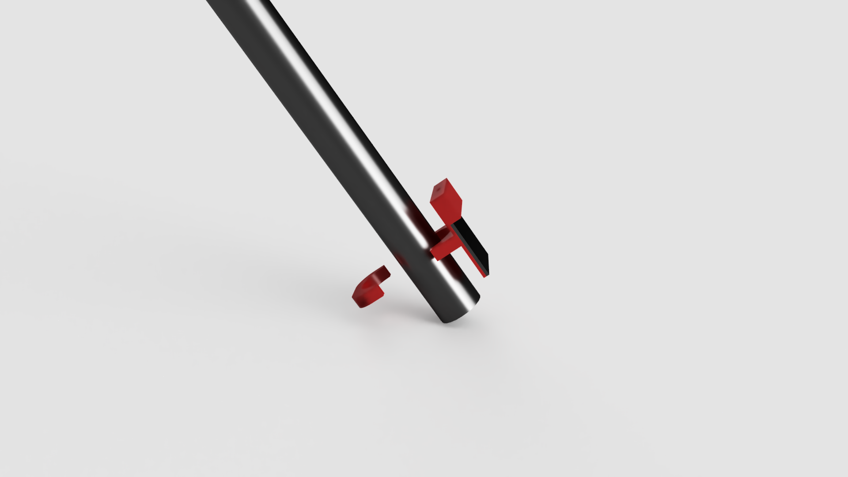
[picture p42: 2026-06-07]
3D Design/Photo Preview/Rain Sensor.PNG

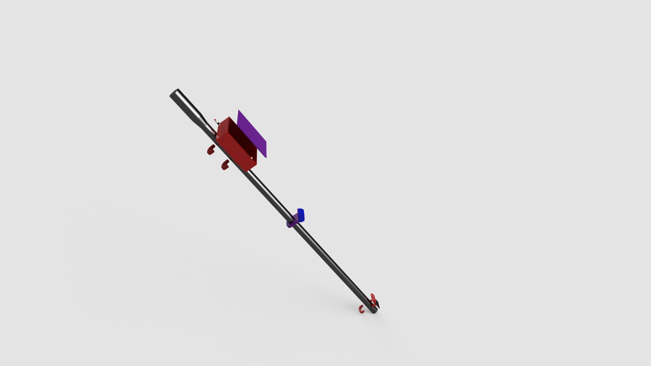
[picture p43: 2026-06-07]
3D Design/Photo Preview/Right.png

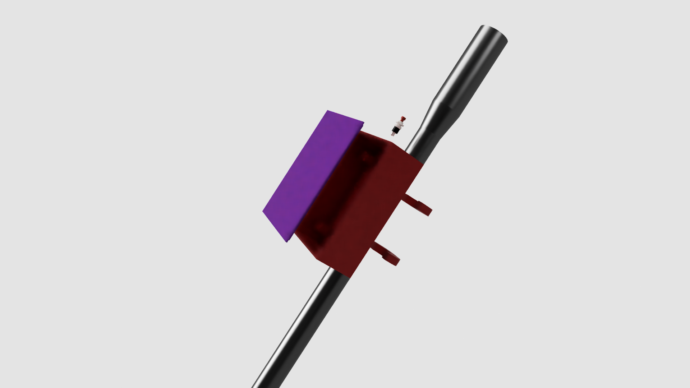
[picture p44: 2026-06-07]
3D Design/Photo Preview/Master Box.png

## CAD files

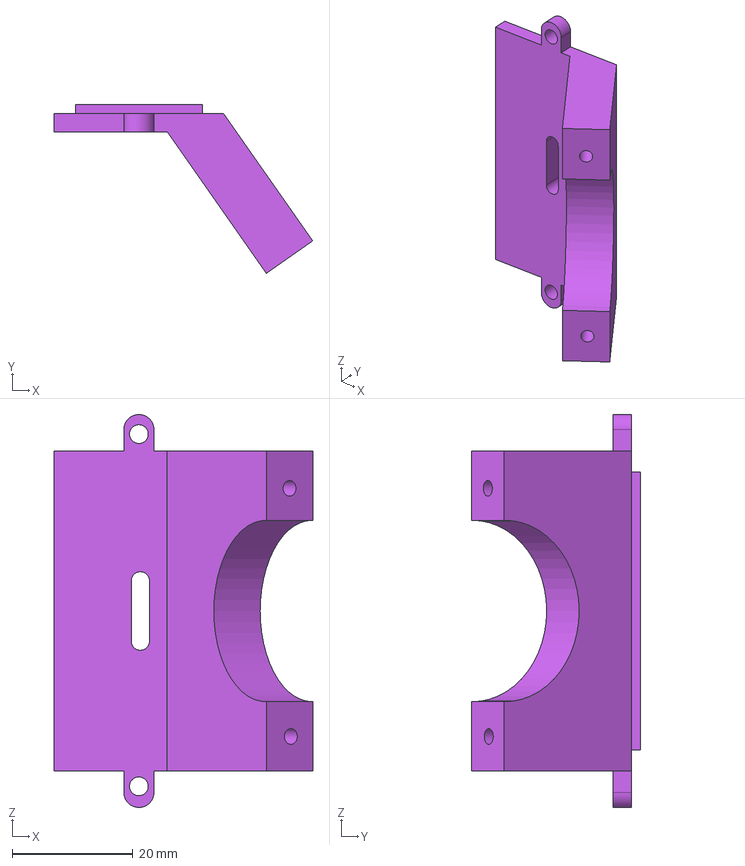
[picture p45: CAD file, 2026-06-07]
3D Design/3D File/Ultrasonic Back Cover.step
42.8 x 27.9 x 65.0 mm

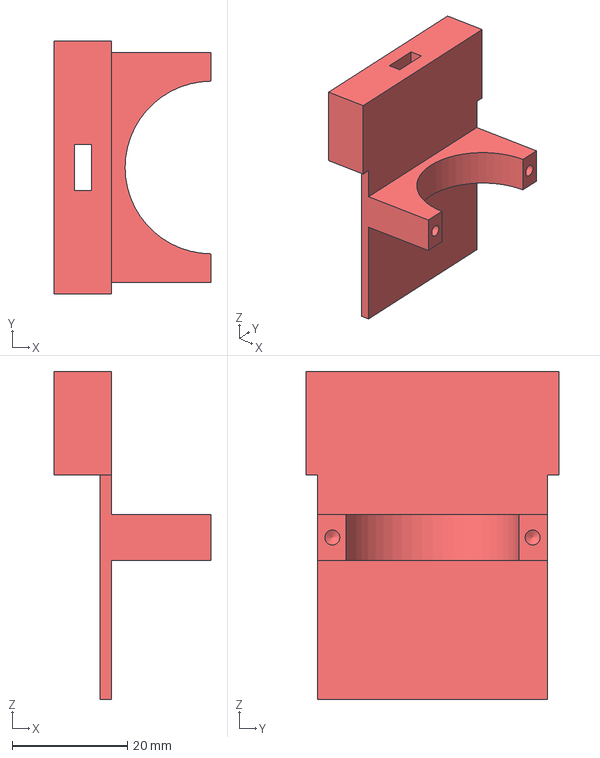
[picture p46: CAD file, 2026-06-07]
3D Design/3D File/Rain Sensor Case.step
27.2 x 44.0 x 57.0 mm

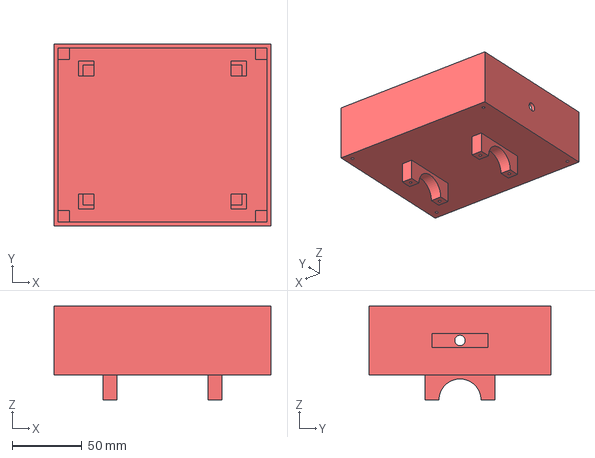
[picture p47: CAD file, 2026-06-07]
3D Design/3D File/Master Box.step
155.0 x 130.0 x 66.9 mm

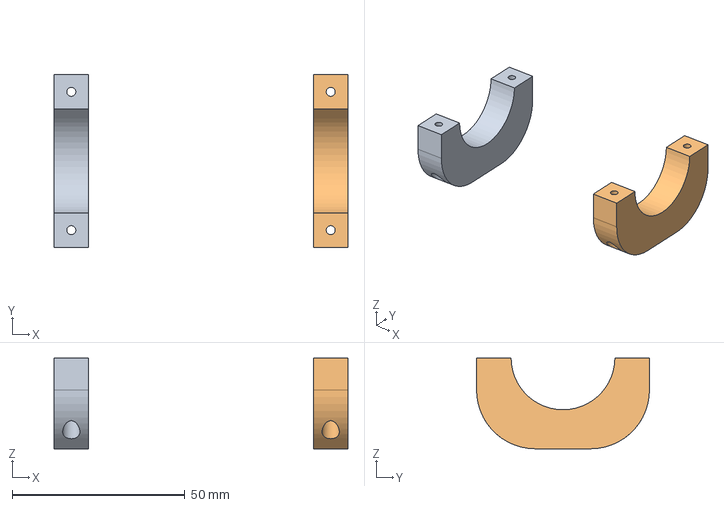
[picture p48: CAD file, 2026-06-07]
3D Design/3D File/Master Clamp.step
85.0 x 50.0 x 26.2 mm

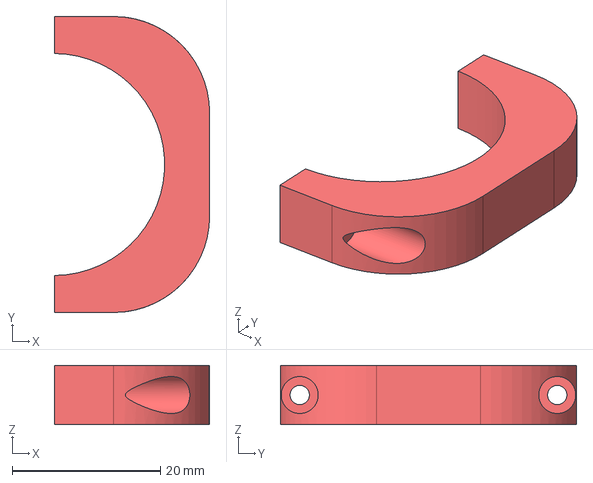
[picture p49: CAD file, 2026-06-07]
3D Design/3D File/Rain Sensor Clamp.step
21.0 x 40.0 x 8.00 mm

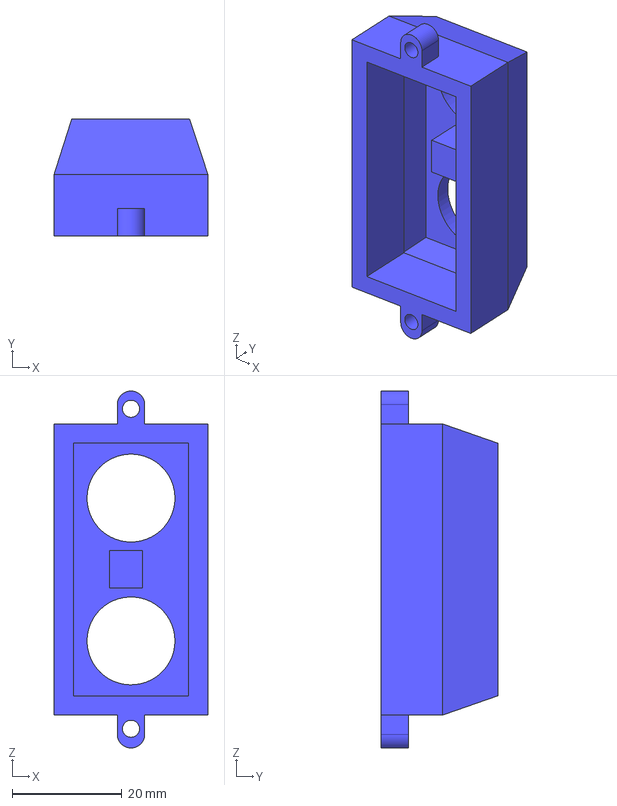
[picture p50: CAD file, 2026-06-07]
3D Design/3D File/Ultrasonic Front Cover.step
28.0 x 21.2 x 65.0 mm

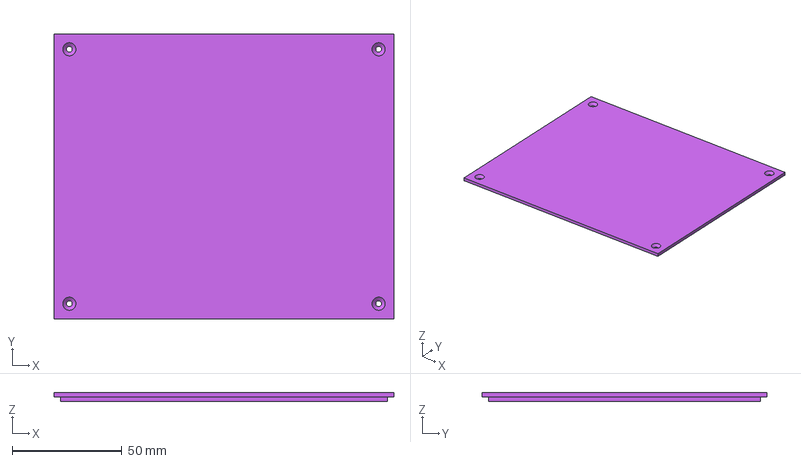
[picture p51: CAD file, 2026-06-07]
3D Design/3D File/Master Front Cover.step
155.0 x 130.0 x 4.00 mm

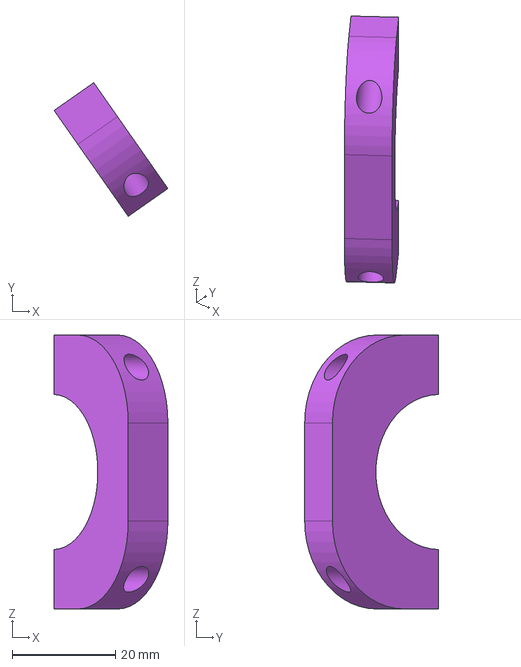
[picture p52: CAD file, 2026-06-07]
3D Design/3D File/Ultrasonic Clamp.step
22.0 x 25.9 x 53.0 mm

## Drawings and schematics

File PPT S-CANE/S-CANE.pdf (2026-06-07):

## Detect, Alert, Protect. SMART CANE

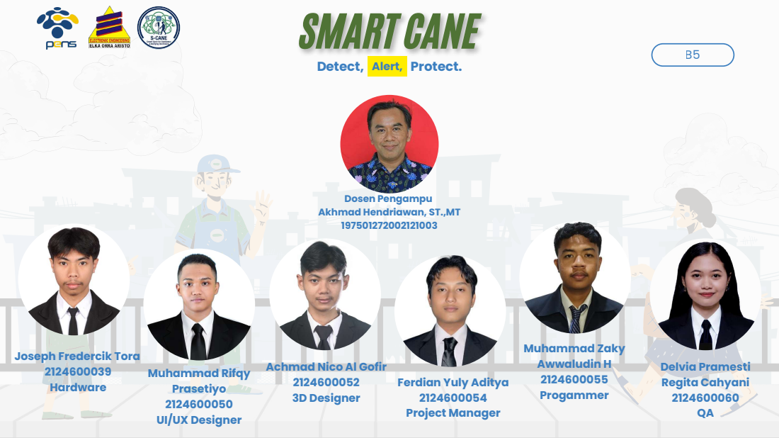
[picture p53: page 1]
Muhammad Zaky Awwaludin H 2124600055 Progammer; Delvia Pramesti Regita Cahyani 2124600060 QA; Joseph Fredercik Tora 2124600039 Hardware; Alert,

Dosen Pengampu
Akhmad Hendriawan, ST.,MT

Achmad Nico Al Gofir
3D Designer

Muhammad Rifqy
Prasetiyo
UI/UX Designer

Ferdian Yuly Aditya
Project Manager

# MIND-MAP

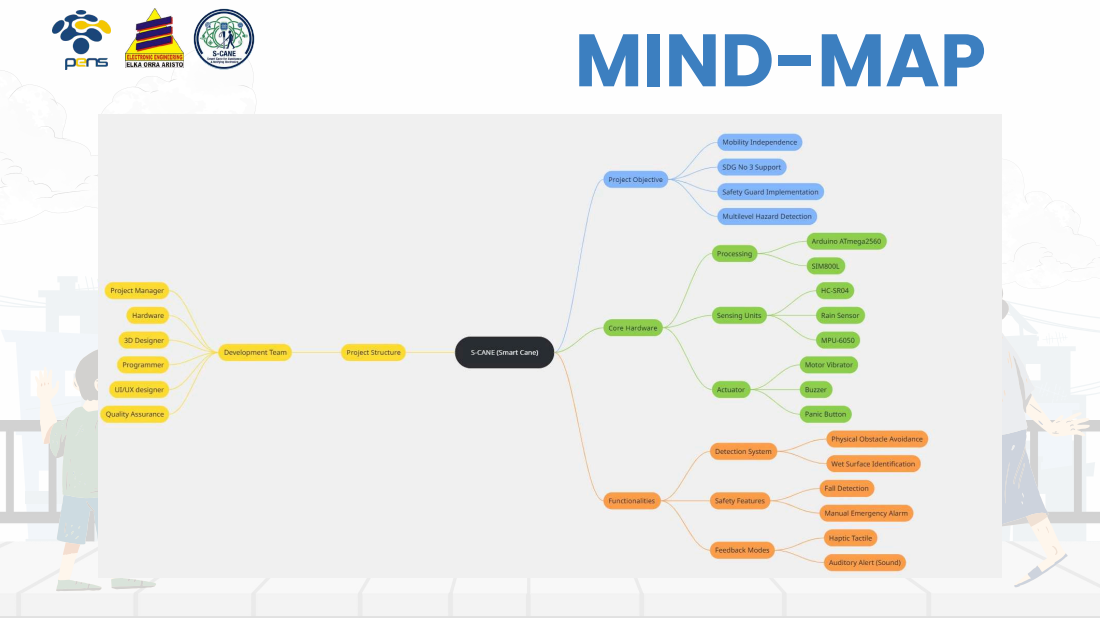
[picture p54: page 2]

# THE PROBLEM

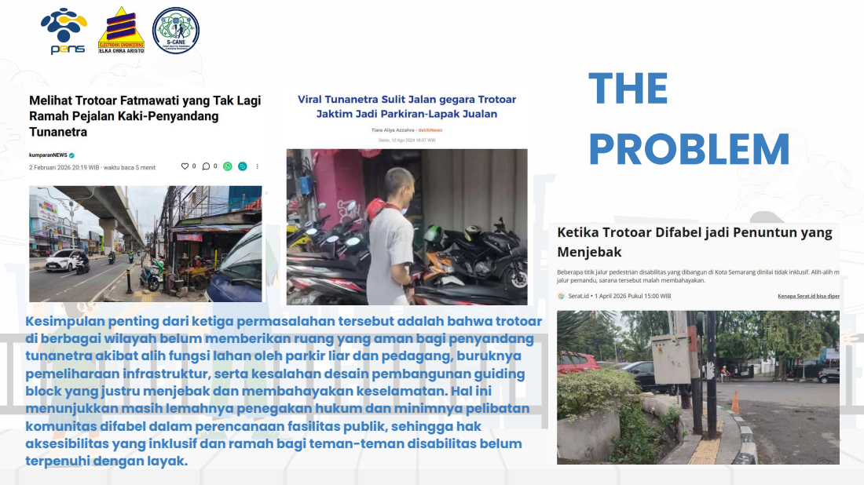
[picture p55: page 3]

Kesimpulan penting dari ketiga permasalahan tersebut adalah bahwa trotoar
di berbagai wilayah belum memberikan ruang yang aman bagi penyandang
tunanetra akibat alih fungsi lahan oleh parkir liar dan pedagang, buruknya
pemeliharaan infrastruktur, serta kesalahan desain pembangunan guiding
block yang justru menjebak dan membahayakan keselamatan. Hal ini
menunjukkan masih lemahnya penegakan hukum dan minimnya pelibatan
komunitas difabel dalam perencanaan fasilitas publik, sehingga hak
aksesibilitas yang inklusif dan ramah bagi teman-teman disabilitas belum
terpenuhi dengan layak.

# ROOT CAUSE & MATRIK KEPUTUSAN

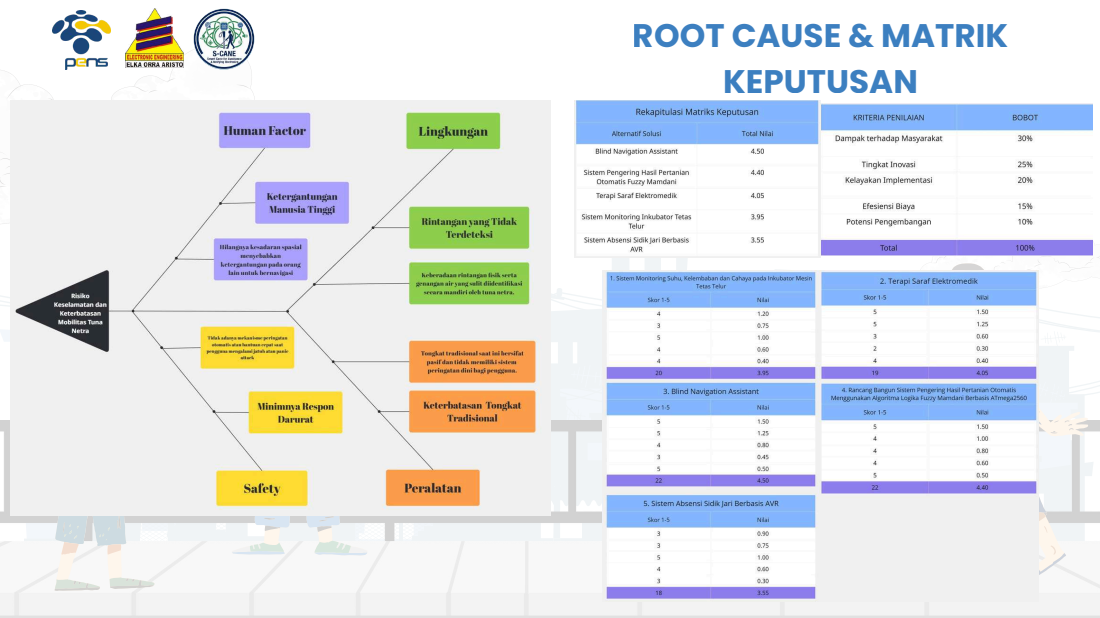
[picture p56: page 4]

# SDGs IMPACT

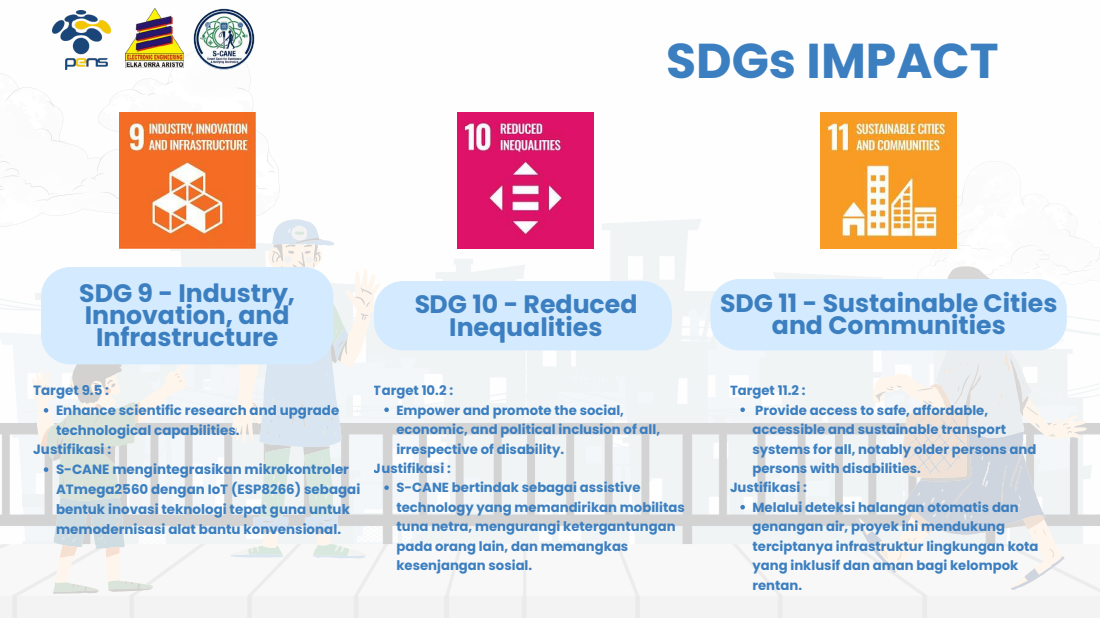
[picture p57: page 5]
SDG 10 - Reduced Inequalities; SDG 9 - Industry, Innovation, and Infrastructure

SDG 11 - Sustainable Cities
and Communities

Target 9.5 :
Enhance scientific research and upgrade
technological capabilities.
Justifikasi :
S-CANE mengintegrasikan mikrokontroler
ATmega2560 dengan IoT (ESP8266) sebagai
bentuk inovasi teknologi tepat guna untuk
memodernisasi alat bantu konvensional.

Target 10.2 :
Empower and promote the social,
economic, and political inclusion of all,
irrespective of disability.
S-CANE bertindak sebagai assistive
technology yang memandirikan mobilitas
tuna netra, mengurangi ketergantungan
pada orang lain, dan memangkas
kesenjangan sosial.

Target 11.2 :
Provide access to safe, affordable,
accessible and sustainable transport
systems for all, notably older persons and
persons with disabilities.
Melalui deteksi halangan otomatis dan
genangan air, proyek ini mendukung
terciptanya infrastruktur lingkungan kota
yang inklusif dan aman bagi kelompok
rentan.

# TABEL I/O

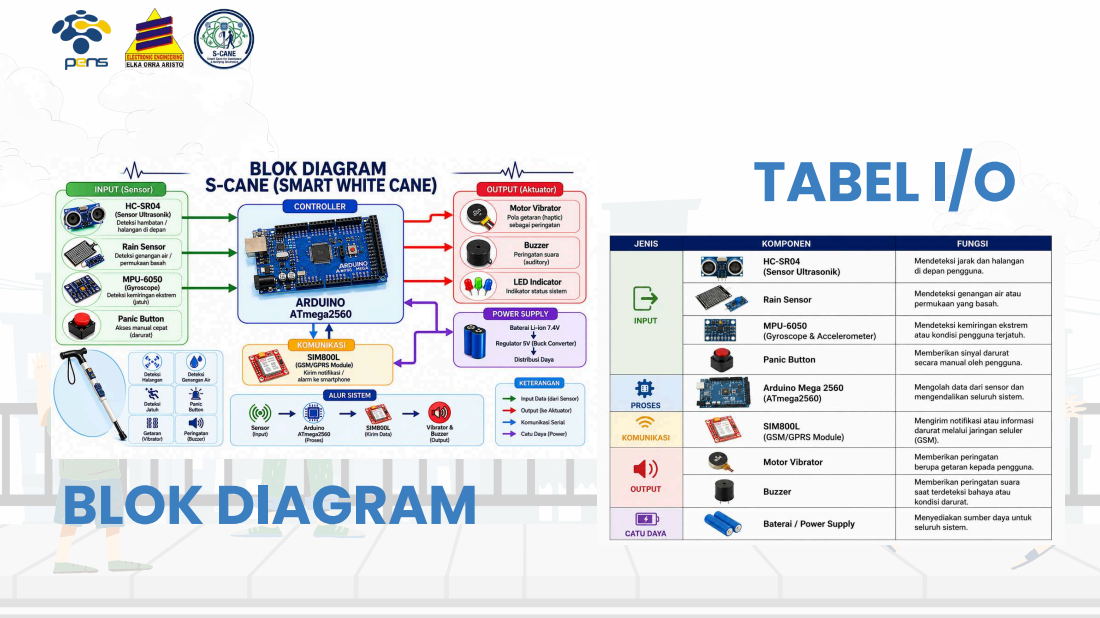
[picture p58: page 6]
BLOK DIAGRAM

# UI UX Design

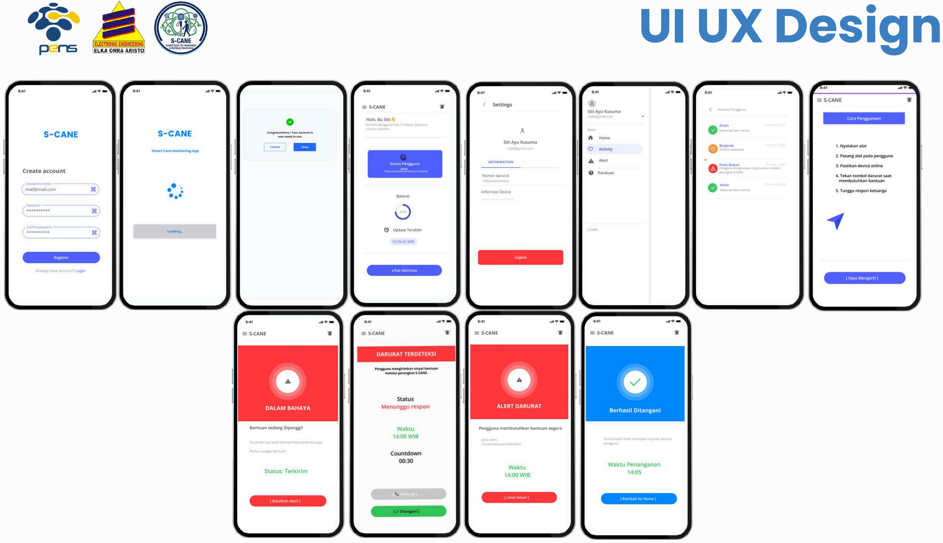
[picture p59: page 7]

P

i

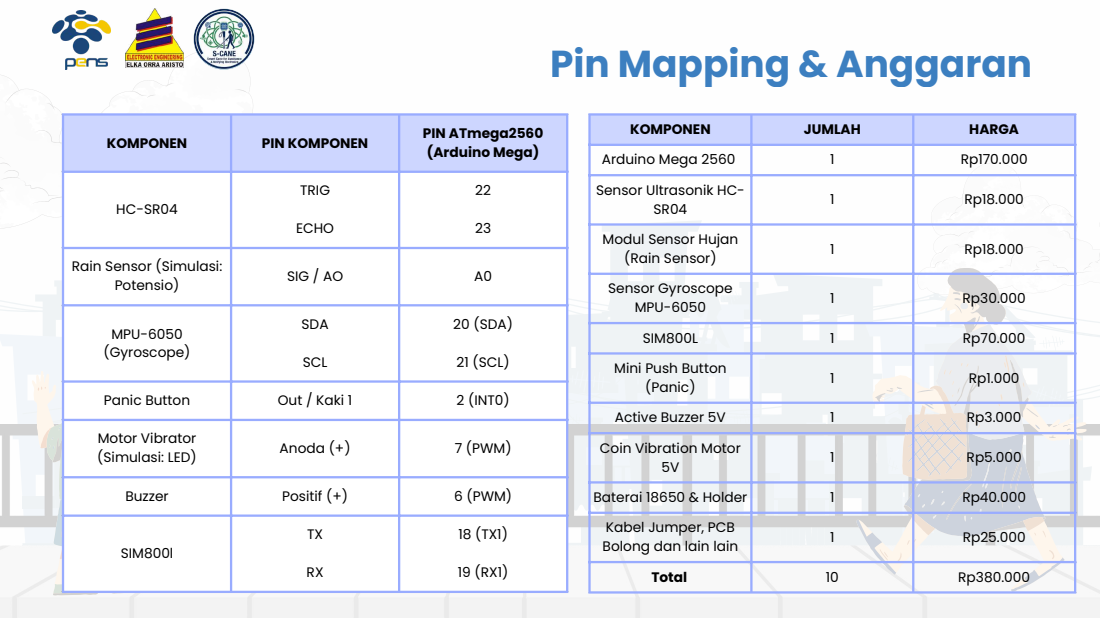
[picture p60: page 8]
Sim; ula; sitif; SIM; Mini P; nic; tiv; oin; Vib; tio; old; olo

A r d uin o M e g a 2 5 6 0 | 1 | R p 1 7 0.0 0 0
S e n s o r Ult r a s o nik H C -S R 0 4 | 1 | R p 1 8.0 0 0

H C -S R 0 4 | T RIG E C H O | 2 2 2 3

M o d ul S e n s o r H u j a n ( R ain S e n s o r ) | 1 | R p 1 8.0 0 0

R ain S e n s o r ( Sim ula si: Potensio) | SIG / A O | A 0

P a nic B u t t o n

M o t o r Vib r a t o r

t e r
K | n lain lain | , B | 1 | R p 2 5.0 0 0

SIM 8 0 | R X | X 1 )

# ACTIVITY LOG

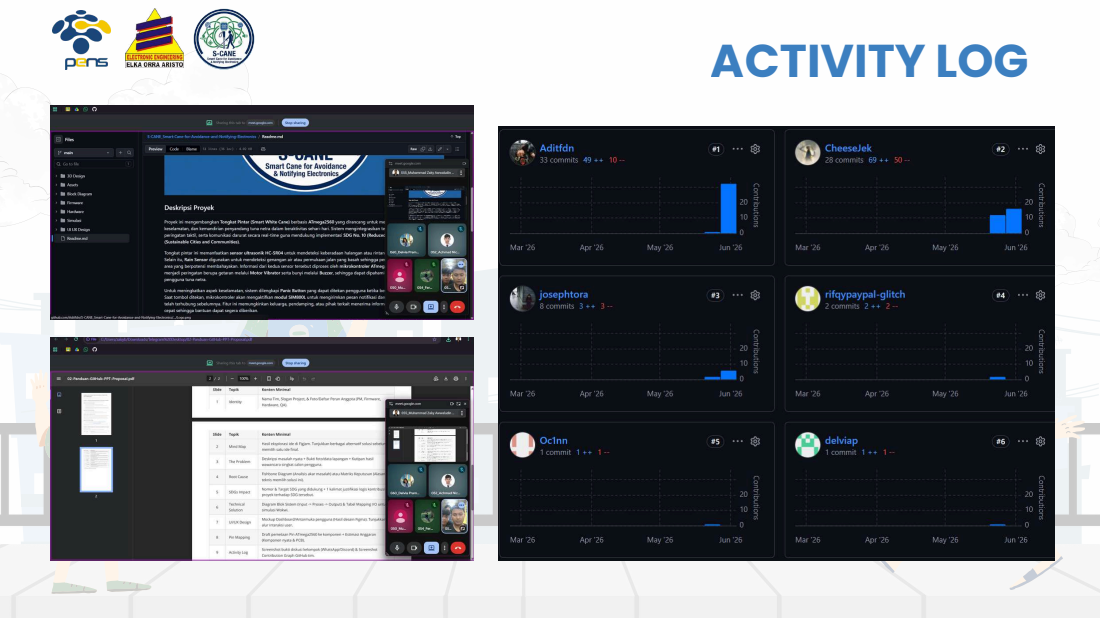
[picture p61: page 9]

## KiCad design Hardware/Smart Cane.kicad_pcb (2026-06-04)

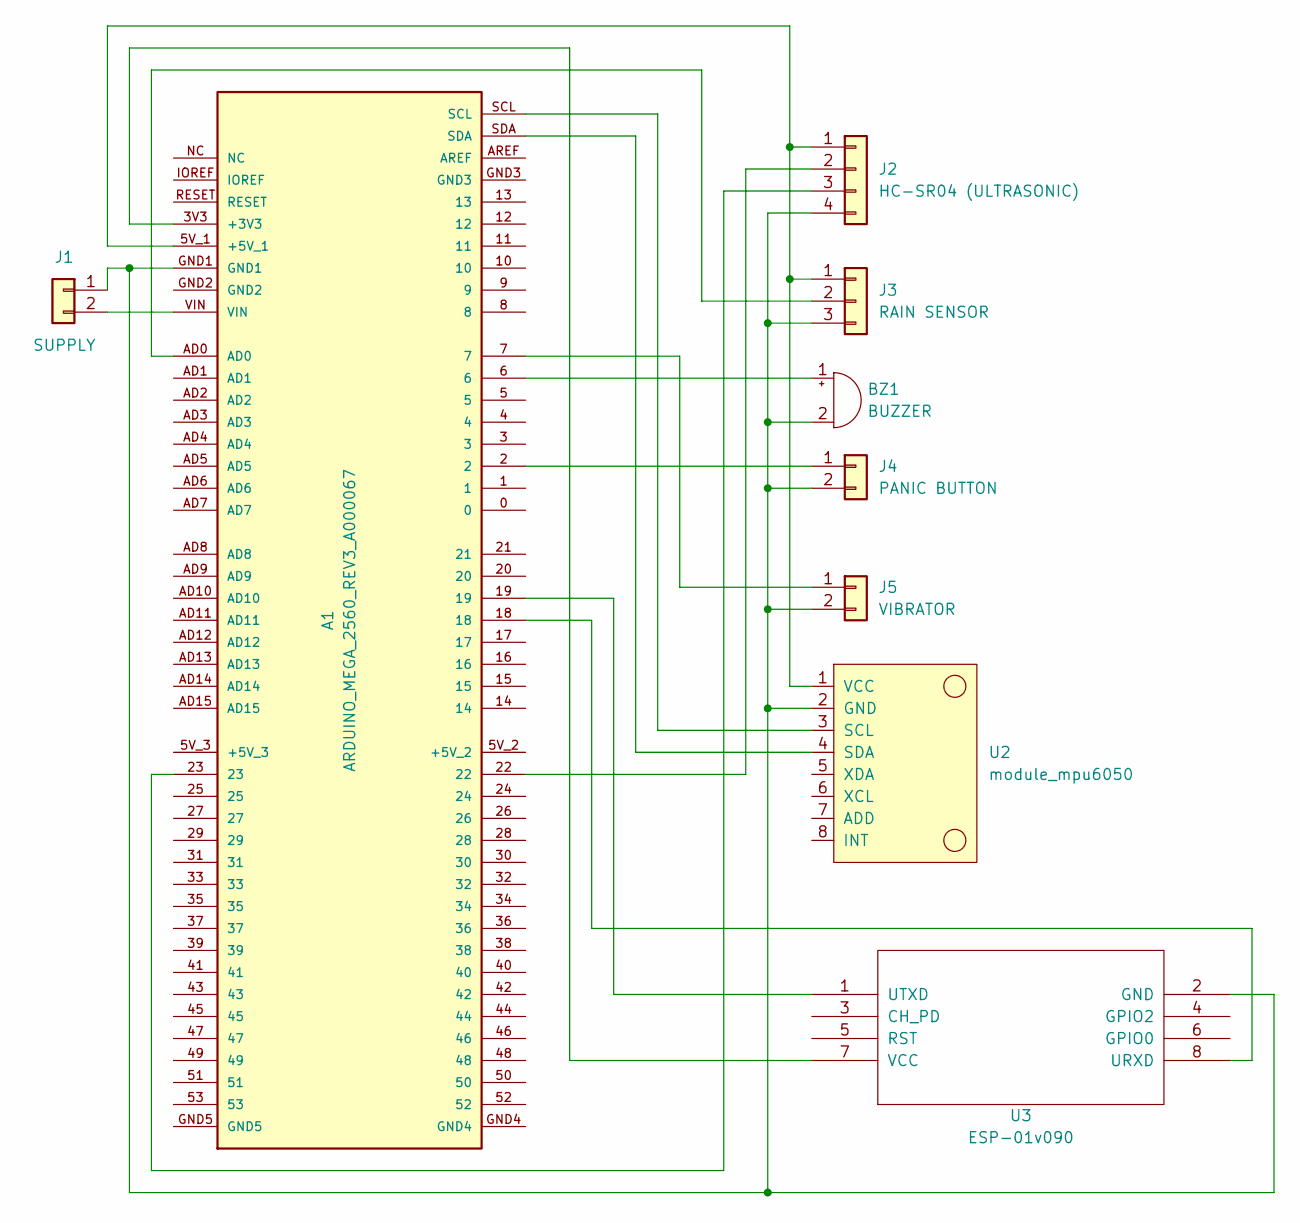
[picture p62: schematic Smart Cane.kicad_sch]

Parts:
A1: ARDUINO_MEGA_2560_REV3_A000067; ARDUINO_ARDUINO_MEGA_2560_REV3_A000067; PARTREV 3
BZ1: BUZZER; Buzzer_12x9.5RM7.6
J1: SUPPLY; Stocko_MKS_1652-6-0-202_1x2_P2.50mm_Vertical
J2: HC-SR04 (ULTRASONIC); Stocko_MKS_1654-6-0-404_1x4_P2.50mm_Vertical
J3: RAIN SENSOR; Stocko_MKS_1653-6-0-303_1x3_P2.50mm_Vertical
J4: PANIC BUTTON; Stocko_MKS_1652-6-0-202_1x2_P2.50mm_Vertical
J5: VIBRATOR; Stocko_MKS_1652-6-0-202_1x2_P2.50mm_Vertical
U2: module_mpu6050
U3: ESP-01v090; ESP-01

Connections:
unnamed: A1.3V3 (+3V3), U3.7 (VCC)
unnamed: A1.5V_1 (+5V_1), J2.1, J3.1, U2.1 (VCC)
unnamed: A1.6, BZ1.1 (+)
unnamed: A1.GND1, BZ1.2 (-), J1.1, J2.4, J3.3, J4.2, J5.2, U2.2 (GND), U3.2 (GND)
unnamed: A1.VIN, J1.2
unnamed: A1.22, J2.2
unnamed: A1.23, J2.3
unnamed: A1.AD0, J3.2
unnamed: A1.2, J4.1
unnamed: A1.7, J5.1
unnamed: A1.SCL, U2.3 (SCL)
unnamed: A1.SDA, U2.4 (SDA)
unnamed: A1.18, U3.8 (URXD)
unnamed: A1.19, U3.1 (UTXD)

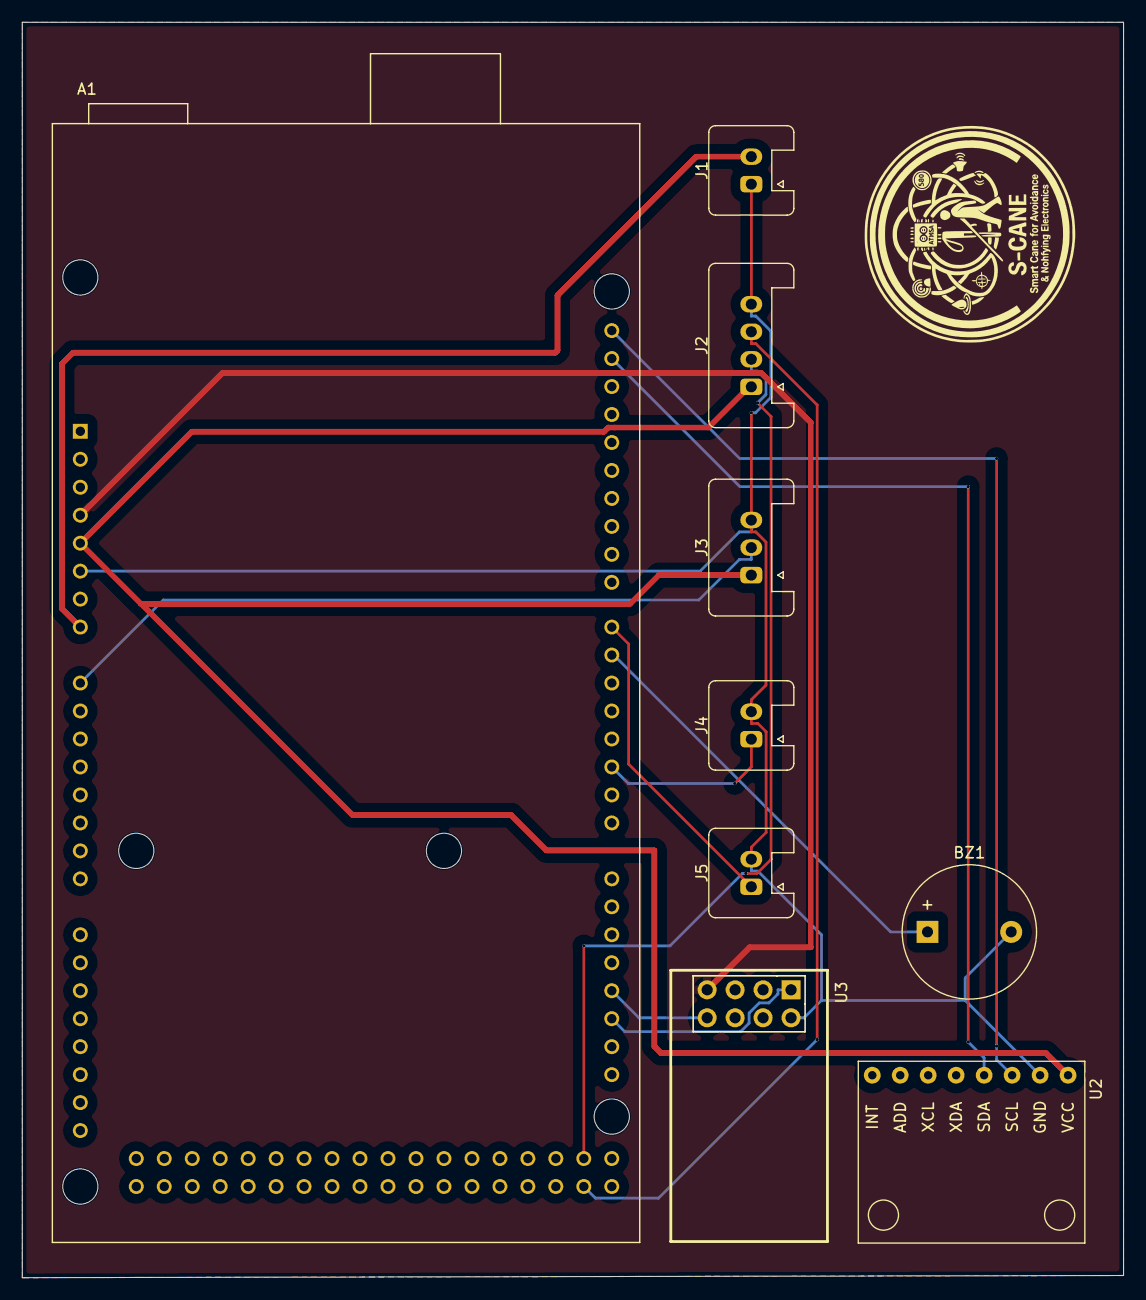
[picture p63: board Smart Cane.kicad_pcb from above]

Board: 2 copper layers, 100.0 x 114.0 mm, 9 parts (0 on the bottom side), 14 nets.

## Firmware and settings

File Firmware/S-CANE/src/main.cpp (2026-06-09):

#include <Arduino.h>
#include <Wire.h>
#include <avr/io.h>
#include <avr/interrupt.h>
#include <util/delay.h>
#include <MPU6050.h>

// ── Pin definitions ─────────────────────────────
// ATmega2560 port mapping:
// Pin 22 = PA0 (TRIG), Pin 23 = PA1 (ECHO)
// Pin 6  = PH3 (BUZZER, OC4A), Pin 7 = PH4 (VIBRATOR, OC4B)
// Pin 2  = PE4 (PANIC, INT4)
// A0 = PF0 (ADC0), A1 = PF1 (ADC1)

#define TRIG_PIN    22
#define ECHO_PIN    23
#define BUZZER_PIN  6
#define VIB_PIN     7
#define PANIC_PIN   2

#define RAIN_CH     0   // A0 = ADC channel 0
#define BAT_CH      1   // A1 = ADC channel 1

MPU6050 mpu;

// ── ADC ─────────────────────────────────────────
void adc_init() {
  ADMUX  = (1 << REFS0);                    // referensi AVcc
  ADCSRB = 0;                               // MUX5=0, channel 0-7
  ADCSRA = (1 << ADEN)                      // ADC enable
         | (1 << ADPS2)
         | (1 << ADPS1)
         | (1 << ADPS0);                   // prescaler 128 → 125kHz @ 16MHz
}

uint16_t adc_read(uint8_t ch) {
  ADMUX  = (1 << REFS0) | (ch & 0x07);     // set channel, jaga REFS
  ADCSRB &= ~(1 << MUX5);                  // channel 0-7, bukan 8-15
  ADCSRA |= (1 << ADSC);                   // mulai konversi
  while (ADCSRA & (1 << ADSC));            // tunggu selesai
  return ADC;                               // baca hasil 10-bit
}

void uart0_init(uint32_t baud) {
  uint16_t ubrr = F_CPU / 16 / baud - 1;
  UBRR0H = (uint8_t)(ubrr >> 8);
  UBRR0L = (uint8_t)(ubrr);
  UCSR0B = (1 << TXEN0) | (1 << RXEN0);    // TX dan RX enable
  UCSR0C = (1 << UCSZ01) | (1 << UCSZ00); // frame 8N1
}

void uart0_putc(char c) {
  while (!(UCSR0A & (1 << UDRE0)));        // tunggu buffer kosong
  UDR0 = c;
}

void uart0_puts(const char *s) {
  while (*s) uart0_putc(*s++);
}

void uart0_putnum(long n) {
  if (n < 0) { uart0_putc('-'); n = -n; }
  if (n == 0) { uart0_putc('0'); return; }
  char buf[12];
  uint8_t i = 0;
  while (n > 0) { buf[i++] = '0' + (n % 10); n /= 10; }
  // reverse buffer supaya urutan digit benar
  uint8_t j = 0, k = i - 1;
  while (j < k) { char t = buf[j]; buf[j] = buf[k]; buf[k] = t; j++; k--; }
  for (uint8_t x = 0; x < i; x++) uart0_putc(buf[x]);
}

// ── UART1 (Serial ke SIM800L) ────────────────────
void uart1_init(uint32_t baud) {
  uint16_t ubrr = F_CPU / 16 / baud - 1;
  UBRR1H = (uint8_t)(ubrr >> 8);
  UBRR1L = (uint8_t)(ubrr);
  UCSR1B = (1 << TXEN1);                   // TX saja, tidak butuh RX
  UCSR1C = (1 << UCSZ11) | (1 << UCSZ10); // frame 8N1
}

void uart1_putc(char c) {
  while (!(UCSR1A & (1 << UDRE1)));
  UDR1 = c;
}

void uart1_puts(const char *s) {
  while (*s) uart1_putc(*s++);
}

// ── HC-SR04 ──────────────────────────────────────
// pulseIn() tetap dipakai karena implementasi bare metal
// membutuhkan timer capture yang konflik dengan tone()
long hcsr04_cm() {
  digitalWrite(TRIG_PIN, LOW);
  delayMicroseconds(2);
  digitalWrite(TRIG_PIN, HIGH);
  delayMicroseconds(10);
  digitalWrite(TRIG_PIN, LOW);
  long dur = pulseIn(ECHO_PIN, HIGH, 30000); // timeout 30ms
  return dur * 0.034 / 2;
}

// ── GPIO bare metal untuk vibrator ───────────────
// Pin 7 = PH4
void vib_on() {
  DDRH  |=  (1 << PH4);  // set output
  PORTH |=  (1 << PH4);  // set HIGH
}

void vib_off() {
  DDRH  |=  (1 << PH4);
  PORTH &= ~(1 << PH4);  // set LOW
}

// ── Baca panic button bare metal ─────────────────
// Pin 2 = PE4
uint8_t panic_read() {
  return (PINE & (1 << PE4)) ? 1 : 0; // 0 = ditekan (LOW), 1 = lepas
}

// ── Kirim SMS darurat ────────────────────────────
void kirim_sms() {
  uart0_puts("Mengirim SMS via SIM800L...\r\n");
  uart1_puts("AT+CMGS=\"+6281234567890\"\r\n");
  _delay_ms(1000);
  uart1_puts("Peringatan S-CANE: Pengguna dalam kondisi DARURAT! ");
  uart1_puts("Tombol panic ditekan atau pengguna terdeteksi jatuh.");
  uart1_putc(26);   // CTRL+Z → eksekusi kirim SMS
  _delay_ms(2000);
}

// ────────────────────────────────────────────────
void setup() {
  adc_init();
  uart0_init(9600);
  uart1_init(9600);

  // GPIO init
  pinMode(TRIG_PIN,   OUTPUT);
  pinMode(ECHO_PIN,   INPUT);
  pinMode(BUZZER_PIN, OUTPUT);
  DDRH  |=  (1 << PH4);              // VIB_PIN output
  DDRE  &= ~(1 << PE4);              // PANIC_PIN input
  PORTE |=  (1 << PE4);              // pullup internal PANIC

  Wire.begin();
  mpu.initialize();
  _delay_ms(1000);

  uart0_puts("S-CANE Berhasil Dinyalakan...\r\n");
  uart1_puts("AT+CMGF=1\r\n");
  _delay_ms(500);
}

void loop() {
  // ── Baca semua sensor ────────────────────────
  long     dist  = hcsr04_cm();
  uint16_t air   = adc_read(RAIN_CH);
  uint16_t bat   = adc_read(BAT_CH);

  int16_t ax, ay, az, gx, gy, gz;
  mpu.getMotion6(&ax, &ay, &az, &gx, &gy, &gz);
  int16_t absAz = abs(az);

  uint8_t panic = panic_read(); // 0=ditekan, 1=lepas

  // ── Halangan depan ───────────────────────────
  if (dist > 0 && dist < 50) {
    vib_on();
    tone(BUZZER_PIN, 1000, 100);
  } else {
    vib_off();
  }

  // ── Genangan air ─────────────────────────────
  if (air > 500) tone(BUZZER_PIN, 500, 500);

  // ── Darurat: panic atau tongkat jatuh ────────
  if (panic == 0 || absAz > 12000) {
    tone(BUZZER_PIN, 2000, 0);
    kirim_sms();
    noTone(BUZZER_PIN);
  }

  // ── Kirim data ke browser ─────────────────────
  // Format: DATA:jarak,air,absAz,panicState,bat
  uart0_puts("DATA:");
  uart0_putnum(dist);  uart0_putc(',');
  uart0_putnum(air);   uart0_putc(',');
  uart0_putnum(absAz); uart0_putc(',');
  uart0_putnum(panic); uart0_putc(',');
  uart0_putnum(bat);   uart0_puts("\r\n");

  _delay_ms(200);
}

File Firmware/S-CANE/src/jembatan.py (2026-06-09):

import serial

COM_OUTPUT = "COM2"  # ganti sesuai com0com pasanganmu
WOKWI_HOST = "localhost"
WOKWI_PORT = 4000

print(f"Menghubungkan ke Wokwi RFC2217 port {WOKWI_PORT}...")
wokwi = serial.serial_for_url(
    f"rfc2217://{WOKWI_HOST}:{WOKWI_PORT}",
    baudrate=9600,
    timeout=1
)

print(f"Membuka COM output: {COM_OUTPUT}...")
com_out = serial.Serial(COM_OUTPUT, baudrate=9600, timeout=1)

print("Jembatan aktif. Ctrl+C untuk berhenti.\n")

while True:
    try:
        data = wokwi.readline()
        if data:
            teks = data.decode(errors='ignore').strip()
            print(f"[Wokwi] {teks}")
            com_out.write(data)
    except KeyboardInterrupt:
        print("\nDihentikan.")
        break
    except Exception as e:
        print(f"Error: {e}")
        break

wokwi.close()
com_out.close()

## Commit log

2026-06-01 Create KiCad Schematic
2026-06-01 KiCad Schematic
2026-06-01 Rename IMG-20260601-WA0041.jpg to KiCad Schematic.jpg
2026-06-01 Add application mockups and user flow diagrams
2026-06-04 Upload kicad_sch file
    [Smart Cane.kicad_sch]
2026-06-04 add kicad_pro and kicad_pcb file
    [Smart Cane.kicad_pcb]
2026-06-07 Rename RAIN SENSOR.PNG to Rain Sensor.PNG
2026-06-07 Rename ULTRASONIC CASE.png to Ultrasonic Case.png
